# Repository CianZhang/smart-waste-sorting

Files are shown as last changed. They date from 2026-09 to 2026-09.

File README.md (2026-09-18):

# 智能垃圾分类——2025 年全国大学生工程实践与创新能力大赛全国一等奖作品

**[▶ 项目演示视频（哔哩哔哩）](https://www.bilibili.com/video/BV18GobY2Efq/)**

项目于我大三期间完成，制作时间为 **2025 年 12 月至 2026 年 3 月**。我负责机械结构设计、STM32 程序编写，以及 YOLOv8 模型的训练与部署；队友 **ccy** 负责树莓派端程序，并在 **zsq** 学长已有 Qt 界面代码的基础上完成界面适配。

这个项目中，我投入最多时间的是机械结构的设计、装配和反复调整。本文既介绍制作方法，也保留实际遇到的问题，希望能为后续复刻和改进提供参考。

基于 **树莓派 5、YOLOv8、STM32F103RCT6 与 CoreXY** 的智能垃圾分类装置。通过视觉识别、托盘倾倒和机械爪抓取完成四类垃圾分拣，并提供触摸界面、投料检测及满载提示。

**[完整制作教程](docs/build-guide.md)** · **[STM32 工程](firmware/stm32/README.md)** · **[树莓派程序](software/raspberry-pi/README.md)** · **[机械模型](hardware/README.md)**

## 项目组成

- 2020 铝型材框架、CoreXY 双步进平台、四舵机机械爪。
- 双舵机托盘、四面同步挡板、红外光幕和四路超声波。
- STM32 控制运动、串口及传感器；树莓派执行 YOLOv8 推理和 Qt/QML 界面。
- 完整教程包含 70 张图片、28 个功能 IO 的接线表、动作参数与省赛程序详解。

## 目录
```text
.
├── README.md
├── docs/                       # 完整制作教程、结构和版本说明
│   ├── build-guide.md
│   └── assets/
├── firmware/stm32/             # 已解压的省赛 Keil 工程
├── software/raspberry-pi/       # 已解压的省赛 Python / QML 应用
├── hardware/mechanical/        # SolidWorks 零件、装配与 STL
├── tools/
│   ├── vision/                 # 图像推理和训练入口
│   ├── calibration/            # 坐标标定程序及采样表
│   └── dataset/legacy/         # 历史采集及标签处理脚本
├── datasets/                   # 配置模板和历史类别顺序
├── models/                     # 部署权重的位置及校验说明
├── references/                 # 厂商资料与机械参考设计索引
├── scripts/                    # 仓库结构检查
├── .github/ISSUE_TEMPLATE/      # 问题反馈模板
└── .local-archive/              # 本地原始资料，Git 忽略
```

## 树莓派环境配置

[SSH、Python 与 YOLOv8 安装命令](docs/raspberry-pi-yolov8-setup.md) · [完整 TXT](docs/搭建yolov8环境.txt)

## 开始制作

1. 按 [制作教程](docs/build-guide.md) 制作框架与机构，完成单模块接线和标定。

2. 在 Keil 中打开 `firmware/stm32/Project.uvprojx`，核对开发板时钟与引脚；已知修正点见教程。

3. 按 [模型说明](models/README.md) 准备 `software/raspberry-pi/yolo/best.pt`，核对类别名称。

4. 在树莓派准备应用依赖，检查摄像头、串口和显示环境，然后从仓库根目录启动：

   ```sh
   sh software/raspberry-pi/run.sh
   ```

5. 通过界面进入识别页完成串口解锁，确认回零与上电等待结束，再进行空载及投料测试。

脚本会切换到正确的应用目录，不需要修改应用中的 QML、模型及图片相对路径。依赖清单尚不是经过实机验证的版本锁定文件。

## 参与与致谢

提交改动时说明使用的硬件、软件及模型版本，记录实际测试结果；参见 [贡献说明](CONTRIBUTING.md)。

作者负责机械结构、STM32 及模型训练部署，队友 ccy 负责树莓派程序，Qt 界面基于 zsq 学长的工作。

使用的第三方资料与贡献者见 [第三方资料与致谢](THIRD_PARTY_NOTICES.md)。

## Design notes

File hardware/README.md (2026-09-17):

# 机械模型

`mechanical/` 保存本项目的 SolidWorks 零件、装配和 STL，保留原文件名及 `XY平台/`、`垃圾桶/` 子目录，避免主动打乱零件关系。

先读 [制作教程](../docs/build-guide.md)，再按自己的实物尺寸打印。打开装配后仍需在 SolidWorks 检查引用、配合和干涉；本次未执行 CAD 软件验证，也未生成未经检查的打印导出件。

Woodcore 参考包保存在本地归档，不混入本项目制造零件。参考来源见 [第三方资料与致谢](../THIRD_PARTY_NOTICES.md)。

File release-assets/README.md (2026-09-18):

# 完整资源下载

[GitHub Release](https://github.com/CianZhang/smart-waste-sorting/releases/tag/resources-v1)

部署权重已随源码仓库提供。以下大型附件需要从 Release 单独下载，源码 ZIP 不包含这些附件。

| 附件 | 大小 |
| --- | ---: |
| [training-data-and-history.zip](https://github.com/CianZhang/smart-waste-sorting/releases/download/resources-v1/training-data-and-history.zip) | 1483.67 MB |
| [stepper-motor-vendor-resources.zip](https://github.com/CianZhang/smart-waste-sorting/releases/download/resources-v1/stepper-motor-vendor-resources.zip) | 458.77 MB |
| [legacy-projects-and-provincial-originals.zip](https://github.com/CianZhang/smart-waste-sorting/releases/download/resources-v1/legacy-projects-and-provincial-originals.zip) | 202.93 MB |
| [1.mp4](https://github.com/CianZhang/smart-waste-sorting/releases/download/resources-v1/1.mp4) | 158.4 MB |
| [yolov8.zip.part001](https://github.com/CianZhang/smart-waste-sorting/releases/download/resources-v1/yolov8.zip.part001) | 1500.0 MB |
| [yolov8.zip.part002](https://github.com/CianZhang/smart-waste-sorting/releases/download/resources-v1/yolov8.zip.part002) | 1500.0 MB |
| [yolov8.zip.part003](https://github.com/CianZhang/smart-waste-sorting/releases/download/resources-v1/yolov8.zip.part003) | 978.8 MB |

## 附件用途

- `1.mp4`: 下载后放入 `software/raspberry-pi/qml/1.mp4`.
- `training-data-and-history.zip`: 训练图片、标签、历史权重、训练结果与训练工程，保留原始目录结构。不同轮次的类别顺序不可直接混用。
- `stepper-motor-vendor-resources.zip`: 张大头步进电机完整说明书、工具、例程和演示视频。
- `legacy-projects-and-provincial-originals.zip`: 旧版 STM32 工程（含编译产物）及省赛原始压缩包。
- `yolov8.zip.part001` 至 `part003`：原始 yolov8.zip 的字节分卷，必须全部下载后合并，不能单独解压。

## 合并 yolov8.zip

macOS / Linux:

```sh
cat yolov8.zip.part001 yolov8.zip.part002 yolov8.zip.part003 > yolov8.zip
```

Windows CMD:

```bat
copy /b yolov8.zip.part001+yolov8.zip.part002+yolov8.zip.part003 yolov8.zip
```

合并完成后可解压。完整文件的 SHA-256：

```text
67cd5b0eae3dfe495bd9983304eb3f1da0dc6049562c12e1c48cc26f418390c0  yolov8.zip
```

附件校验值见 [SHA256SUMS.txt](SHA256SUMS.txt)，来源、文件数量与大小见 [manifest.json](manifest.json)。macOS 使用 `shasum -a 256 -c SHA256SUMS.txt`，Linux 使用 `sha256sum -c SHA256SUMS.txt`。

本地附件实体保存在可见的 `release-assets/` 文件夹，Git 只记录说明与校验清单。原始资料保留在 `.local-archive/original/`。系统镜像与个人初始化资料不在本次发布范围内。历史代码和模型按原样提供，未执行程序或加载模型。

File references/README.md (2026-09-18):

# 参考资料索引

完整厂商资料保留在本地 `.local-archive/original/张大头步进电机资料/`，包含 ZDT_X42_V2、Emm_V5.0 及刷入教程。它们不随本仓库默认提交；接线前应根据实际使用的驱动器版本确认文档。

Woodcore 参考包位于本地 `.local-archive/original/建模/Woodcore XY-CORE by Rics_3D - 2555558/`。原始来源是 [Thingiverse 上的 Woodcore XY-CORE](https://www.thingiverse.com/thing:2555558)，相关来源见 [第三方资料与致谢](../THIRD_PARTY_NOTICES.md)。

STM32 参数参考 [ST 官方数据手册](https://www.st.com/resource/en/datasheet/stm32f103rc.pdf)。

厂商安装包、固件工具和完整镜像保留在本地归档。

## 补充资源下载

训练图片、标签、历史权重与结果、电机厂商完整资料、旧版工程及编译产物、省赛原始压缩包、展示视频和 `yolov8.zip` 已整理为 [GitHub Release 附件](https://github.com/CianZhang/smart-waste-sorting/releases/tag/resources-v1)。分类、还原方式与校验值见 [资源下载说明](../release-assets/README.md)。本地附件位于根目录可见的 `release-assets/` 文件夹，原始归档继续保留。部署权重 `software/raspberry-pi/yolo/best.pt` 已直接纳入源码仓库。

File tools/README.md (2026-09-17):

# 辅助工具

## 图像测试

从仓库根目录执行，输入图片不会连接相机或 STM32：

```sh
python3 tools/vision/test.py --source datasets/local/test_images
```

需要提前准备图片和 [部署模型](../models/README.md)。也可通过 `--weights` 指定其他本地权重，默认输出为 `outputs/test_result/result_0.jpg` 等。

## 训练

```sh
python3 tools/vision/train.py --weights models/local/initial.pt --data datasets/local/data.yaml --epochs 500
```

示例中的文件需要自行准备。训练和图像测试入口已改为显式传参，不再依赖原电脑的绝对目录。默认输出位于根目录 `outputs/`，由 Git 忽略。`--help` 不加载模型或第三方依赖。

## 坐标标定

`calibration/main.py` 用最小二乘拟合二维映射；`main.c` 与 Excel 表为对应资料。程序中的标定点来自既有机构，必须在新机构上重新采集，见制作教程。

## 历史采集与标签工具

`dataset/legacy/` 中保存采集、改名、标签映射和数据拆分脚本，以及 `classes.txt`。这些脚本保留历史路径和修改行为，用于查看制作过程；不要直接批量运行，其中部分会原地改写标签或重命名图片。

历史类别合并有不同版本，必须与权重类别定义核对；完整数据仍在本地归档。本次没有对数据集重新划分或改写标签。

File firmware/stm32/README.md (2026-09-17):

# STM32 省赛工程

使用 `Project.uvprojx`，目标器件为 STM32F103RC，控制板按 STM32F103RCT6 接线。工程记录的编译器为 ARMCC V5.06 update 5（build 528）。

- `User/main.c`：完整分拣入口。
- `Hardware/`：舵机、CoreXY、传感器、串口及动作组合。
- `System/`：延时与 TIM7 配置。
- `Start/`：启动文件及系统时钟。
- `Library/`：随工程保留的 STM32 标准外设库，版权头保留。

完整 IO 表、回零时序、角度、坐标及已知问题见 [制作教程](../../docs/build-guide.md)。目录中的文件不一定都参与编译，以工程文件列表为准；不要把同名 PWM 实现重复加入工程。

本目录按省赛源码保存，未自动应用教程里的控制逻辑修正。特别是第四路 Echo PB15 的初始化需要按教程处理。编译缓存和个人 Keil 窗口状态不纳入 Git。

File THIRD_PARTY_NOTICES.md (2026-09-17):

# 第三方资料与致谢

| 内容 | 来源或作者 | 说明 |
| --- | --- | --- |
| 树莓派端程序 | ccy | 省赛应用实现 |
| Qt 界面基础 | zsq | 界面基础与适配参考 |
| Ultralytics YOLO | 项目已有框架副本，版本字符串 8.2.10 | 完整框架留在本地归档，应用通过依赖安装 |
| STM32 标准外设库与启动支持 | 随省赛工程保留的 ST / Arm 相关文件 | 支持控制器初始化与外设驱动 |
| Woodcore XY-CORE | Rics_3D，Thingiverse 2555558 | CoreXY 结构参考，完整参考包留在本地归档 |
| 驱动器手册及工具 | 张大头/Emm 相关资料包 | 本地归档提供硬件参考 |
| OpenCV、pyserial、PySide6 | Python 应用依赖 | 图像处理、串口通信和 Qt 界面 |

感谢以上贡献者及项目提供的代码、设计与资料。

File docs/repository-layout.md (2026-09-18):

# 目录迁移说明

项目根目录仍为原来的“工训赛”文件夹。制作资料组织为公开项目内容和本地原始归档两部分。

## 主要入口

| 内容 | 新位置 |
| --- | --- |
| 项目首页 | [README](../README.md) |
| 详细制作教程 | [build-guide.md](build-guide.md) |
| 教程图片 | `docs/assets/` |
| STM32 工程 | [固件说明](../firmware/stm32/README.md) |
| 树莓派应用 | [应用说明](../software/raspberry-pi/README.md) |
| 机械模型 | [模型目录说明](../hardware/README.md) |
| 训练、测试与标定 | [工具说明](../tools/README.md) |

## 环境配置资料

树莓派 YOLOv8 安装记录已纳入公开目录：[环境配置文档](raspberry-pi-yolov8-setup.md) 与 [完整 TXT](搭建yolov8环境.txt)。TXT 与本地归档文件内容一致。

## 原资料保留位置

所有整理前的根目录项目整体移入 `.local-archive/original/`，保持其原有子目录关系。没有删除原文件，系统镜像和数据也没有重复复制到公开项目。

| 整理前位置 | 原始副本位置 | 提供的公开入口 |
| --- | --- | --- |
| `工训赛-智能垃圾分类.md` | `.local-archive/original/工训赛-智能垃圾分类.md` | `docs/build-guide.md` |
| `工训赛-智能垃圾分类.assets/` | `.local-archive/original/工训赛-智能垃圾分类.assets/` | `docs/assets/` |
| `建模/` | `.local-archive/original/建模/` | `hardware/mechanical/`，独立参考包除外 |
| `代码/省赛代码/` | `.local-archive/original/代码/省赛代码/` | 已解压到固件和应用目录 |
| `代码/坐标映射/` | `.local-archive/original/代码/坐标映射/` | `tools/calibration/` |
| `代码/get_photo/` | `.local-archive/original/代码/get_photo/` | `tools/dataset/legacy/` |
| `代码/树莓派/` | `.local-archive/original/代码/树莓派/` | 可移植入口位于 `tools/vision/` |
| 旧工程、训练数据、镜像、安装包 | `.local-archive/original/代码/` | 本地归档，Git 忽略 |
| `张大头步进电机资料/` | `.local-archive/original/张大头步进电机资料/` | `references/README.md` 提供索引 |

`.local-archive/inventory-before.json` 记录迁移前的相对路径、大小和修改时间；`migration-report.json` 记录整理时的验证结果。两者只保存在本地归档。

## 提交范围

`.gitignore` 排除本地归档、模型、展示视频、推理图片、构建缓存和个人环境文件。部署权重纳入源码仓库，展示视频通过 Release 下载。

公开仓库只包含上述整理后的项目内容；本地原始归档不随 Git 提交上传。

## 补充资源下载

训练图片、标签、历史权重与结果、电机厂商完整资料、旧版工程及编译产物、省赛原始压缩包、展示视频和 `yolov8.zip` 已整理为 [GitHub Release 附件](https://github.com/CianZhang/smart-waste-sorting/releases/tag/resources-v1)。分类、还原方式与校验值见 [资源下载说明](../release-assets/README.md)。本地附件位于根目录可见的 `release-assets/` 文件夹，原始归档继续保留。部署权重 `software/raspberry-pi/yolo/best.pt` 已直接纳入源码仓库。

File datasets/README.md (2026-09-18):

# 数据集与类别配置

完整训练数据留在本地 `.local-archive/original/代码/` 中。新增数据放在 `datasets/local/`，Git 默认忽略该目录。

- `data.example.yaml`：按历史 `classes.txt` 整理的十类模板，必须改路径并核对标签后使用。
- `config-history/`：三轮训练的四类名称和顺序快照；路径使用 `<DATASET_ROOT>` 占位，不能直接拿来训练。

不同轮次的类别编号顺序存在差异，不能仅因为都是四类就互换 YAML、标签和权重。省赛应用按具体物体名称映射到四大类，详见制作教程。

发布数据时应补充来源、类别定义及使用范围。各轮训练质量以实际测试结果为准。

## 补充资源下载

训练图片、标签、历史权重与结果、电机厂商完整资料、旧版工程及编译产物、省赛原始压缩包、展示视频和 `yolov8.zip` 已整理为 [GitHub Release 附件](https://github.com/CianZhang/smart-waste-sorting/releases/tag/resources-v1)。分类、还原方式与校验值见 [资源下载说明](../release-assets/README.md)。本地附件位于根目录可见的 `release-assets/` 文件夹，原始归档继续保留。部署权重 `software/raspberry-pi/yolo/best.pt` 已直接纳入源码仓库。

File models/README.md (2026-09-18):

# 模型权重

部署模型位于 `software/raspberry-pi/yolo/best.pt`，已纳入 Git 仓库，克隆项目即可获得该部署权重。

| 项目 | 内容 |
| --- | --- |
| 来源 | 省赛 Python 3.19 压缩包中的 `yolo/best.pt` |
| 文件大小 | 22536814 字节 |
| SHA-256 | `0e9ade16c99730c9233939a2b89183e47f08c946b4a3c8519184833ff6c6b524` |

原压缩包留在本地 `.local-archive/original/代码/省赛代码/`。原始压缩包与历史训练资料同时提供于 [GitHub Release](https://github.com/CianZhang/smart-waste-sorting/releases/tag/resources-v1)，文件说明见 [资源下载说明](../release-assets/README.md)。

程序使用模型中的物体名称映射到四类垃圾，部署前核对 `model.names`。历史数据含不同类别体系，不能仅按文件名 `best.pt` 判断是否匹配。

自行训练的权重可以暂存于 `models/local/`，该目录由 Git 忽略。没有执行加载或推理验证，也没有从不可信的模型文件反序列化内容。

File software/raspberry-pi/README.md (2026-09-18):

# 树莓派省赛应用

应用入口为本目录的 `main.py`。`qml/main.py` 是另一个界面入口，不作为完整系统启动入口。

## 环境配置命令

项目保存的 Ubuntu 24.04.1 LTS、Python 3.10.16 和 YOLOv8 配置命令已整理为 [环境配置文档](../../docs/raspberry-pi-yolov8-setup.md)，也可查看 [完整 TXT](../../docs/搭建yolov8环境.txt)。这份记录覆盖 YOLOv8 安装；Qt 应用依赖仍需按下文准备。

## 运行准备

需要 ultralytics、OpenCV、pyserial 和 PySide6，依赖名称列在 `requirements.txt`。操作系统、Python、PyTorch 和 Qt 的具体组合仍需在目标树莓派验证，没有把未核实的版本标为可复现环境。

确认以下条件后，从仓库根目录运行：

```sh
sh software/raspberry-pi/run.sh
```

可以通过 `PYTHON` 指定已经配置好的解释器。启动器只切换工作目录并准备结果图片目录，不自动安装软件、不自动修改硬件设置。

| 资源/配置 | 当前使用位置 |
| --- | --- |
| 模型 | `yolo/best.pt` |
| 摄像头 | `main.py` 中 `cv.VideoCapture(0)` |
| 串口 | `main.py` 中 `/dev/ttyAMA0`、115200 |
| 界面 | `qml/main.qml`，布局为 1280 × 800 |
| 推理图片 | `yolo/pics/`，Git 忽略 |
| 展示视频 | `qml/1.mp4`，Git 忽略 |

## 模型和视频

部署模型 `yolo/best.pt` 已纳入 Git 仓库。展示视频请从 [GitHub Release](https://github.com/CianZhang/smart-waste-sorting/releases/tag/resources-v1) 下载 `1.mp4`，放到本目录的 `qml/1.mp4`。

模型来源与校验值见 [模型说明](../../models/README.md)。展示页使用 `qml/1.mp4`，下载后保持文件名和位置一致；不使用展示页时可相应调整界面。没有视频不代表视觉识别代码或模型缺失。

省赛原始压缩包及历史结果图位于本地归档，具体位置见 [目录迁移说明](../../docs/repository-layout.md)。

## 已知行为

代码保留省赛识别和计数逻辑。首次未识别到目标时随机分类、识别前置计数、串口超时不足等问题已在 [完整教程](../../docs/build-guide.md) 中说明。运行前先做模块测试，不把桌面静态检查当作整机验证。

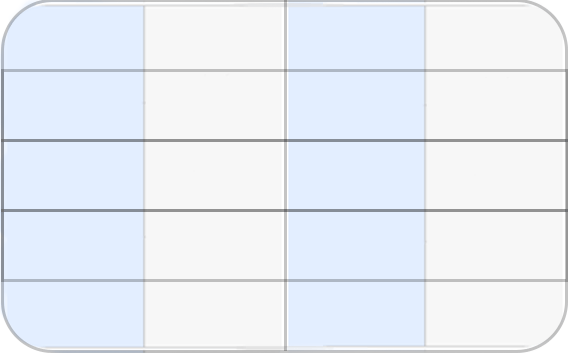
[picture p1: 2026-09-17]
software/raspberry-pi/qml/UI_2.1/p2/images/Page2_15.png

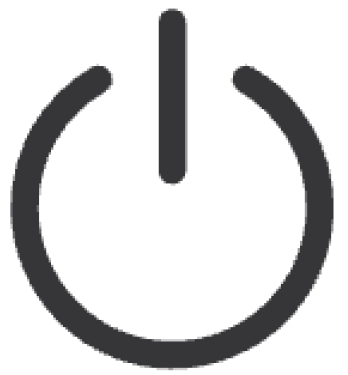
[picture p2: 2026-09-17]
software/raspberry-pi/qml/UI_2.1/p2/images/关机2.png

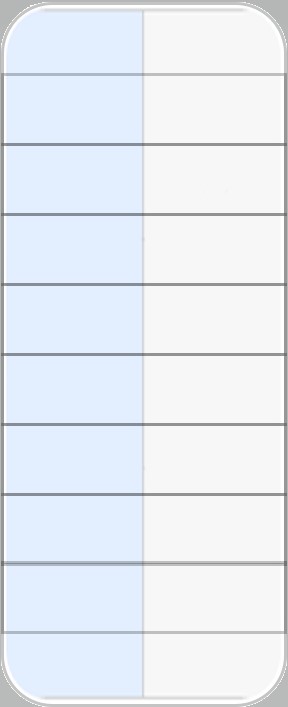
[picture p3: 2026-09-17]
software/raspberry-pi/qml/UI_2.1/p2/images/Page2_05.jpg

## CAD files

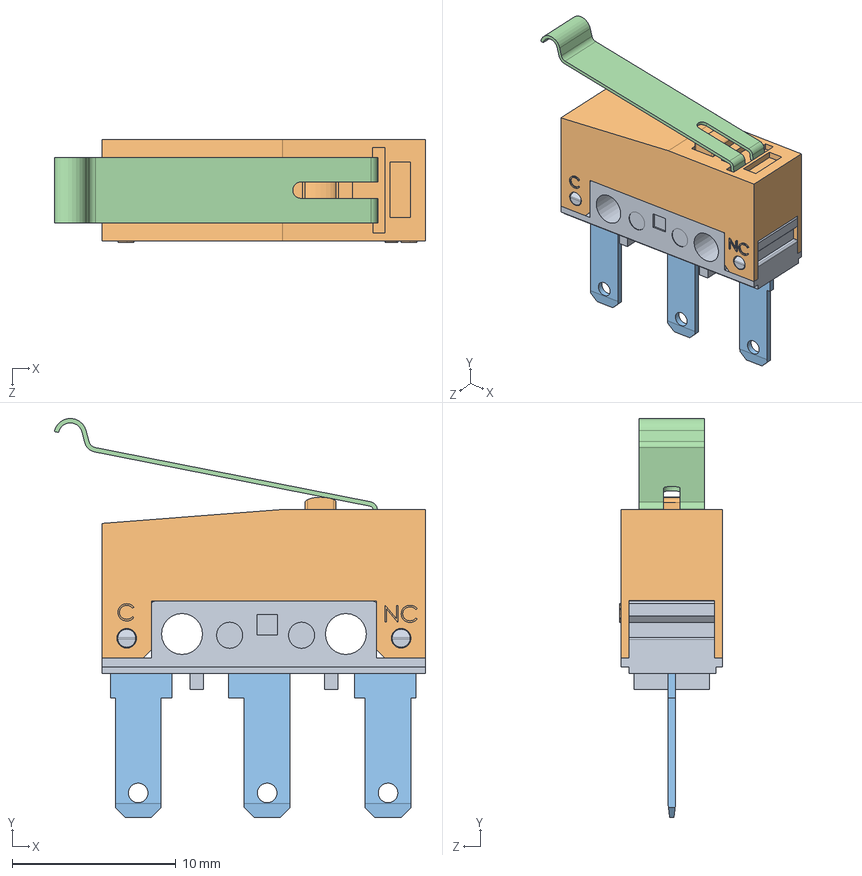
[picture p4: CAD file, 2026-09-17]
hardware/mechanical/垃圾桶/Microswitch-SS-3GL13SL.SLDASM
22.7 x 24.4 x 6.30 mm
limit-switch-bottomcase
limit-switch-top-case
pins
switch_lever

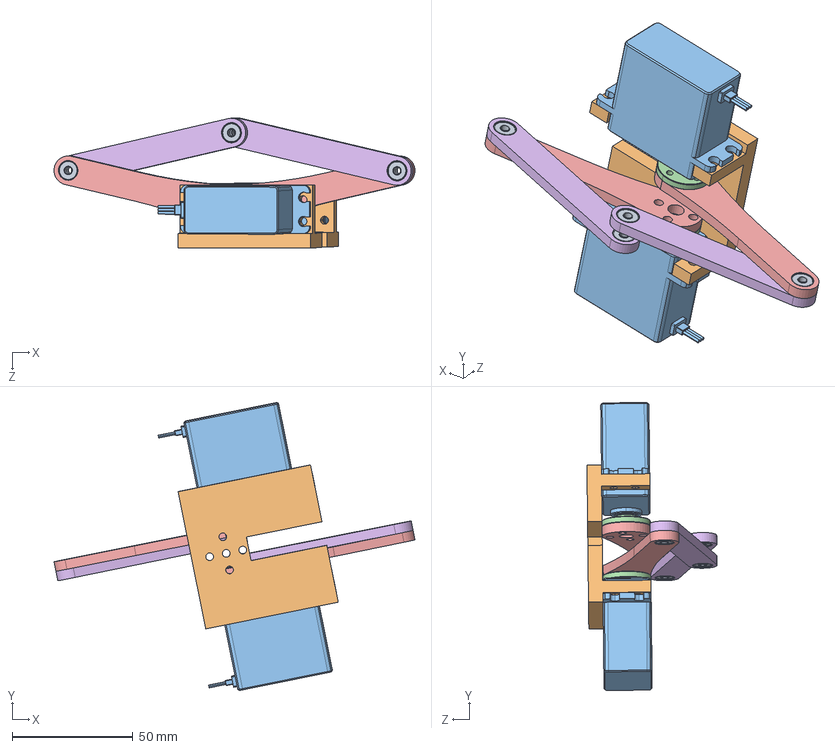
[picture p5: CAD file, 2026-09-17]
hardware/mechanical/垃圾桶/机械爪上.SLDASM
149.6 x 119.3 x 53.9 mm
M3ￖ᳐' x 6
ﾶ滺' x 2
¶æ_Ì x 2
连杆1 x 2
连杆2 x 2

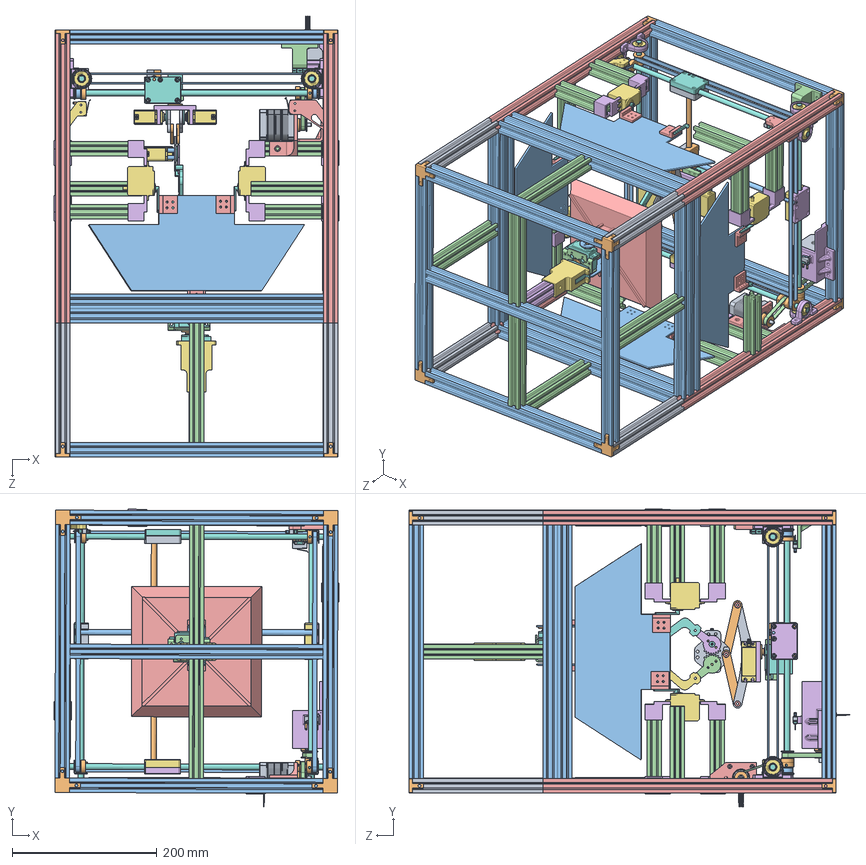
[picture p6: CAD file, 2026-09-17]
hardware/mechanical/垃圾桶/垃圾桶.SLDASM
393.4 x 410.9 x 609.0 mm
11NhomDinhHinh2020（180mm） x 4
欧标2020三维连接件 x 8
11NhomDinhHinh2020（350mm） x 17
11NhomDinhHinh2020（165mm） x 6
11NhomDinhHinh2020（400mm） x 4
11NhomDinhHinh2020（120mm）
11底部舵机固定
11servo x 3
11shaft x 3
Servo disc x 3
11Servo Bracket - long U v3
Servo Bracket - universal.step
托盘
11KP08 x 8
11608RS x 8
8mm光轴（长384mm） x 4
十字滑块1
十字滑块2
8mm光轴（长336mm）
11LM8LUU Long Type Linear Bearing（长24）
11LM8LUU Long Type Linear Bearing x 4
11滑块_右 x 2
11滑块_右盖 x 2
11滑块_左 x 2
11滑块_左盖 x 2
8mm光轴（长335.9mm）
12 8 20铜套
11机械臂单舵机固定
M3ￖ᳐' x 6
ﾶ滺' x 3
¶æ_Ì x 3
连杆1 x 2
连杆2 x 2
Ì×2 x 4
צϰ￫2'
Ì×
צϰ￫'
ￂצ'
抓手左
零件3
同步轮8mm x 10
挡板 x 4
11铝型材2020长100 x 12
11挡板固定 x 8
11舵机铝型材支架 x 8
11舵机1 x 4
11长款舵机固定 x 8
1142BYGH0425 x 2
步进电机同步轮 x 2
同步带示意 x 4
同步带示意上 x 2
步进电机固定架下
步进电机固定架上
碰撞开关固定1
limit-switch-bottomcase x 4
limit-switch-top-case x 4
pins x 4
switch_lever x 4
碰撞开关固定2
碰撞开关固定3

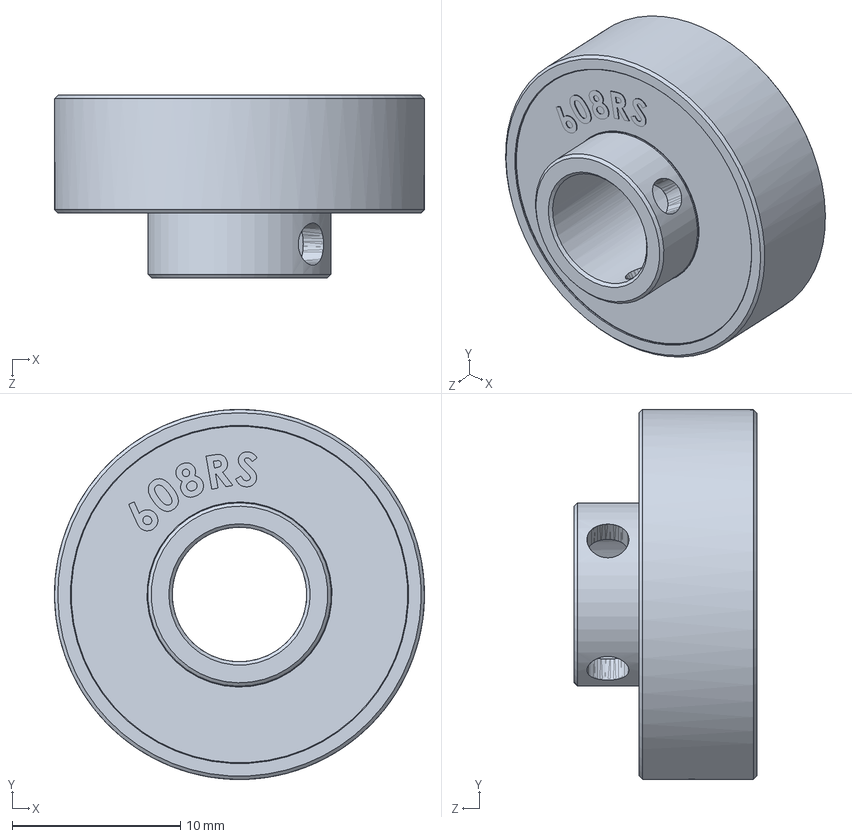
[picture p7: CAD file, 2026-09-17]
hardware/mechanical/垃圾桶/11KP08.SLDASM
22.0 x 22.0 x 10.9 mm

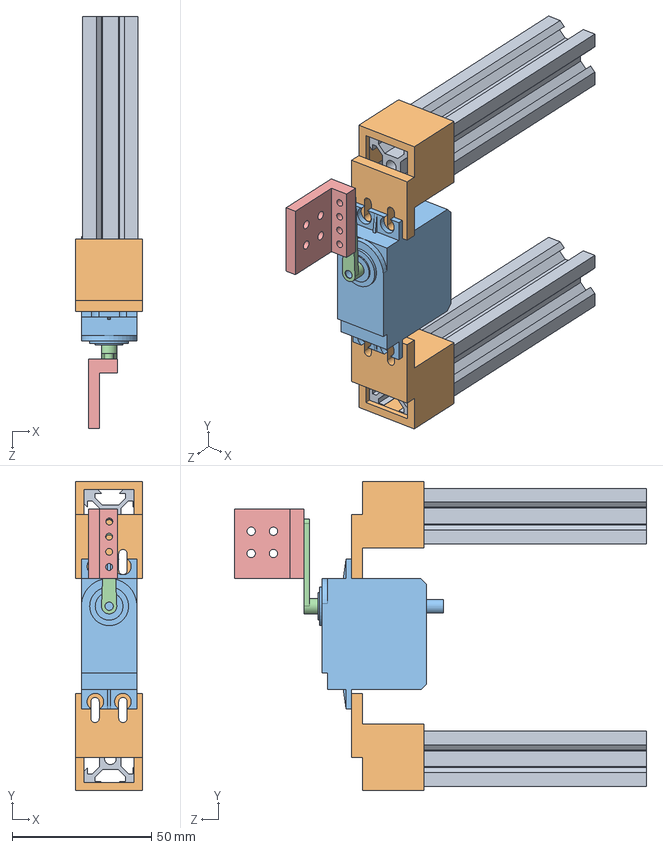
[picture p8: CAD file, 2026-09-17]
hardware/mechanical/垃圾桶/挡板固定舵机.SLDASM
24.0 x 111.2 x 148.1 mm
11铝型材2020长100 x 2
11舵机铝型材支架 x 2
11舵机1
11长款舵机固定
11挡板固定

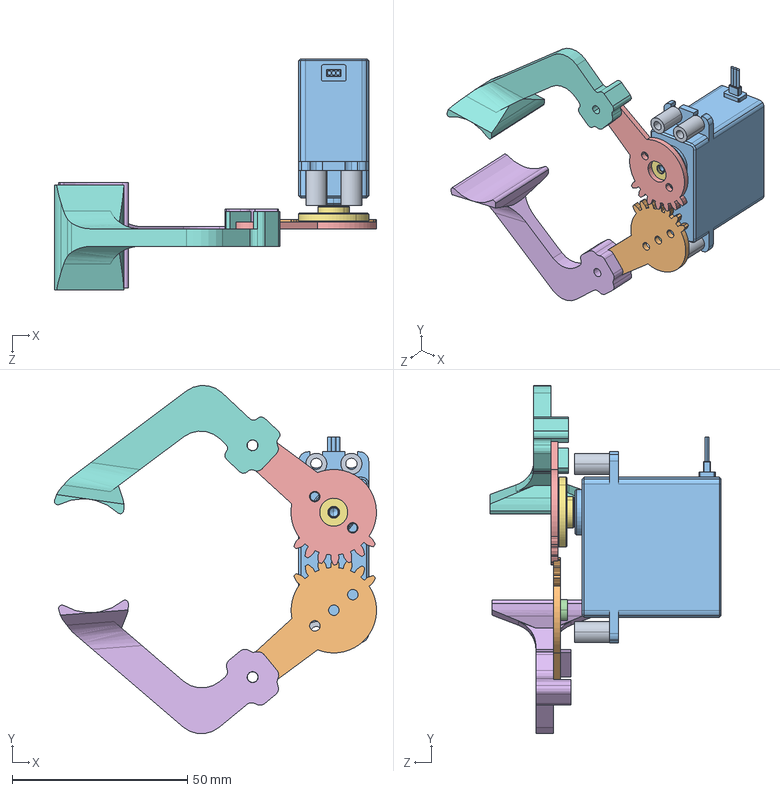
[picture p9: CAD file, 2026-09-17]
hardware/mechanical/垃圾桶/机械爪下.SLDASM
91.9 x 99.2 x 66.0 mm
Ì×2 x 4
צϰ￫2'
ﾶ滺'
Ì×
צϰ￫'
ￂצ'
¶æ_Ì
抓手左

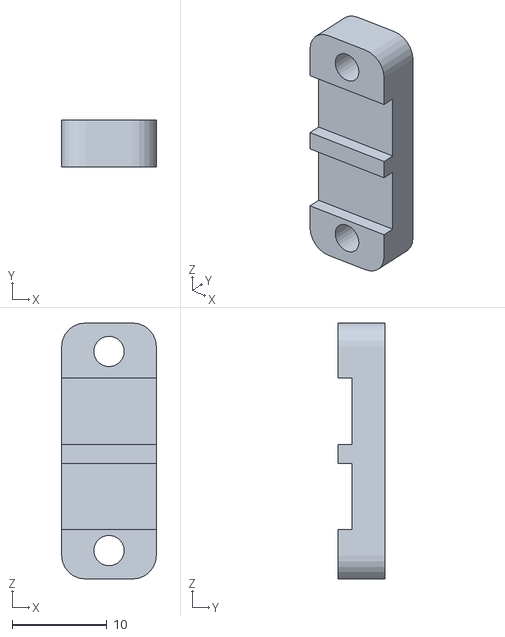
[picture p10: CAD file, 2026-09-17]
hardware/mechanical/XY平台/Riemenklammer.stl
10.0 x 5.00 x 27.0

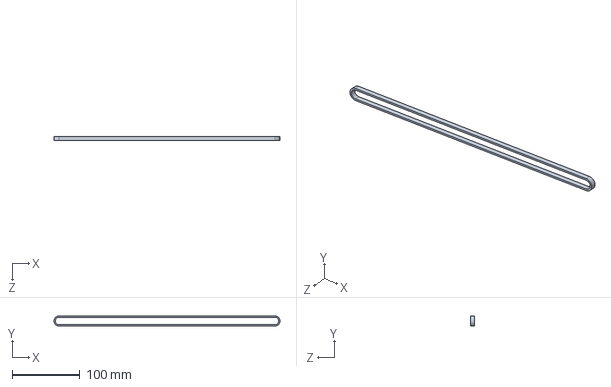
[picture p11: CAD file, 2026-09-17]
hardware/mechanical/垃圾桶/同步带示意.SLDPRT
332.9 x 15.0 x 6.00 mm

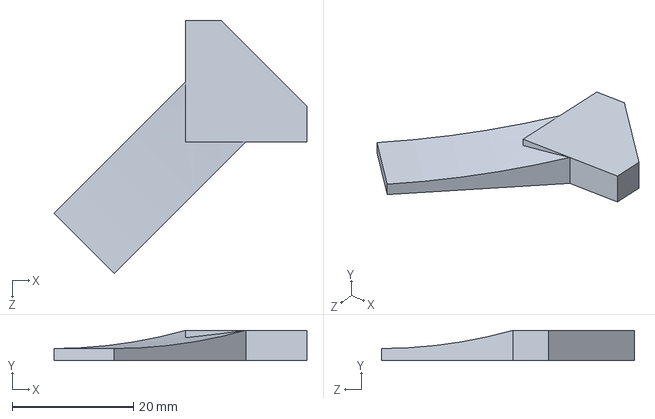
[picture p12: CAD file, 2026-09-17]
hardware/mechanical/超声波固定.SLDPRT
41.7 x 5.00 x 41.7 mm

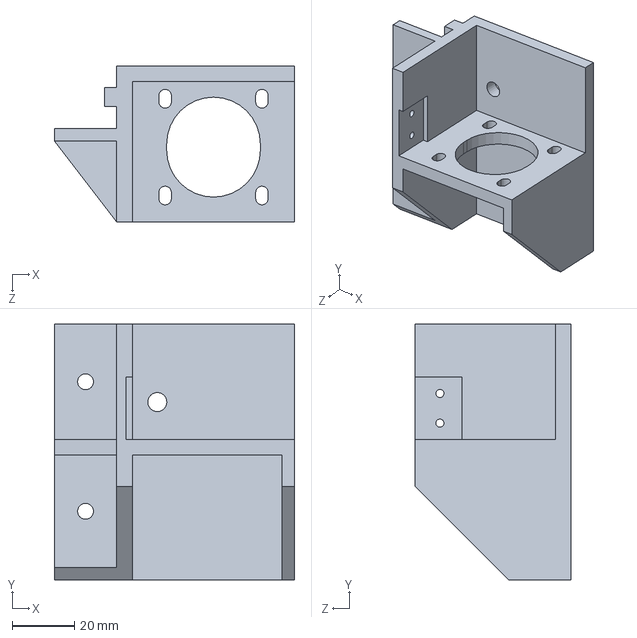
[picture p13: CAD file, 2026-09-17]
hardware/mechanical/XY平台/步进电机支架左.SLDPRT
77.0 x 82.0 x 50.0 mm

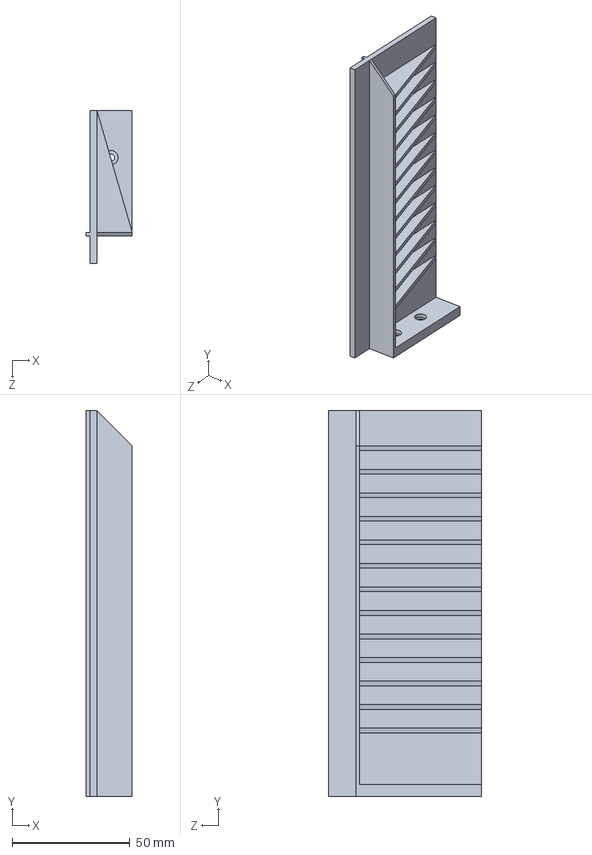
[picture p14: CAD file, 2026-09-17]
hardware/mechanical/压缩面挡板.SLDPRT
19.8 x 164.0 x 65.0 mm

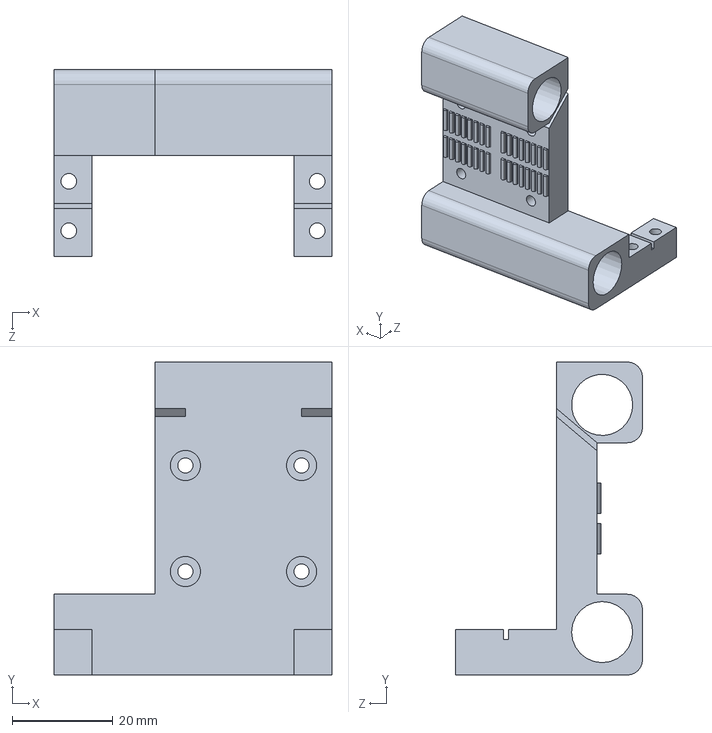
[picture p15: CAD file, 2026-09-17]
hardware/mechanical/XY平台/中心轴 - 副本.SLDPRT
55.0 x 62.0 x 37.0 mm

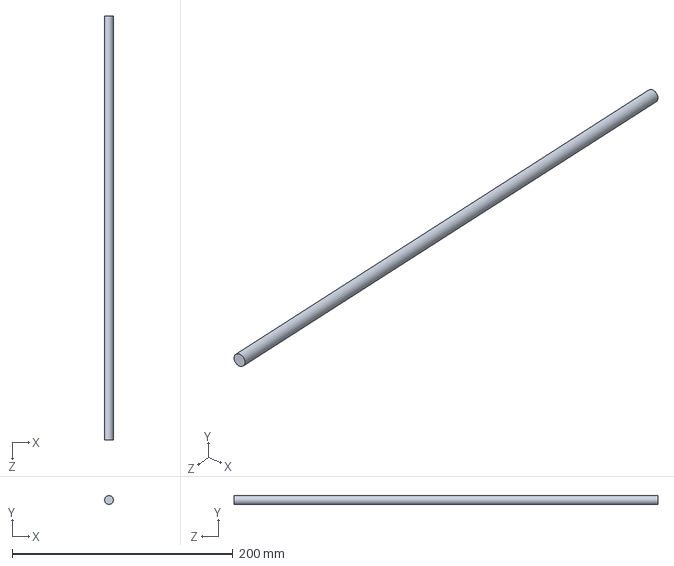
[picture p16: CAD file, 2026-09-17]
hardware/mechanical/垃圾桶/8mm光轴（长384mm）.SLDPRT
8.00 x 8.00 x 384.0 mm

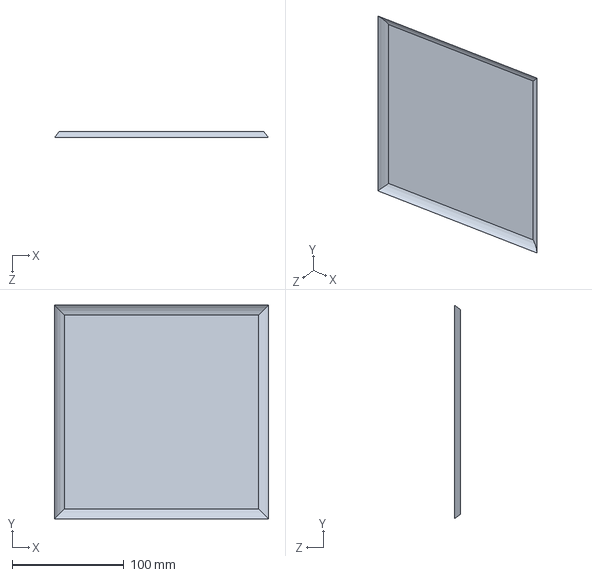
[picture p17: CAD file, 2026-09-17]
hardware/mechanical/托盘覆盖圆滑.SLDPRT
191.3 x 191.3 x 5.79 mm

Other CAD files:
hardware/mechanical/垃圾桶/11MG996R.SLDASM
hardware/mechanical/LED固定.SLDPRT
hardware/mechanical/XY平台/y轴右.SLDPRT
hardware/mechanical/垃圾桶/11机械臂单舵机固定.SLDPRT
hardware/mechanical/XY平台/y轴左.SLDPRT
hardware/mechanical/XY平台/惰轮替代.SLDPRT
hardware/mechanical/XY平台/步进电机支架右.SLDPRT
hardware/mechanical/XY平台/滑轨支架右.SLDPRT
hardware/mechanical/XY平台/滑轨支架左.SLDPRT
hardware/mechanical/侧面柱子固定.SLDPRT
hardware/mechanical/侧面舵机固定.SLDPRT
hardware/mechanical/压缩杆固定.SLDPRT
hardware/mechanical/压缩面.SLDPRT
hardware/mechanical/垃圾桶/1.sldprt
hardware/mechanical/垃圾桶/1142BYGH0425.SLDPRT
hardware/mechanical/垃圾桶/11608RS.SLDPRT
hardware/mechanical/垃圾桶/11KP08.SLDPRT
hardware/mechanical/垃圾桶/11LM8LUU Long Type Linear Bearing.SLDPRT
hardware/mechanical/垃圾桶/11LM8LUU Long Type Linear Bearing（长24）.SLDPRT
hardware/mechanical/垃圾桶/11NhomDinhHinh2020（120mm）.SLDPRT
hardware/mechanical/垃圾桶/11NhomDinhHinh2020（165mm）.SLDPRT
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

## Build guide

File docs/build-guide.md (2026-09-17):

# 工训赛智能垃圾分类装置：从结构制作到省赛程序部署

本项目使用 **树莓派 5 + YOLOv8** 识别垃圾，通过 **STM32F103RCT6、CoreXY 平台、四舵机机械爪和二维云台** 完成分拣，并使用红外光幕、超声波传感器和 Qt 界面实现投料检测、满载提示及操作交互。

项目在我大三期间完成，制作时间为 **2025 年 12 月至 2026 年 3 月**。我负责机械结构设计、STM32 程序以及 YOLOv8 模型训练与部署；队友 **ccy** 负责树莓派端代码，并基于 **zsq** 学长的 Qt 界面完成适配。

本文按实际制作顺序介绍零件、装配、接线、标定和软件流程。软件说明以 `firmware/stm32/` 与 `software/raspberry-pi/` 中展开的 **省赛 3.19 版本**为依据。部分照片属于制作过程中的不同阶段，安装前应核对模型孔位、尺寸和自己的实物。尚未确认的采购规格不作为固定型号推荐。

## 目录

- [系统如何完成一次分拣](#系统如何完成一次分拣)
- [项目文件与制作准备](#项目文件与制作准备)
- [物料清单](#物料清单)
- [机械装配过程](#机械装配过程)
- [STM32F103RCT6 接线与供电](#stm32f103rct6-接线与供电)
- [省赛 STM32 程序详解](#省赛-stm32-程序详解)
- [树莓派视觉、Qt 界面与模型训练](#树莓派视觉qt-界面与模型训练)
- [分阶段调试与整机制作验收](#分阶段调试与整机制作验收)
- [常见问题与待完善项](#常见问题与待完善项)
- [仓库整理与资料发布](#仓库整理与资料发布)
- [致谢与第三方资料](#致谢与第三方资料)

## 系统如何完成一次分拣

投入口红外光幕检测到垃圾后，STM32 等待物体稳定，再请求树莓派拍照。树莓派识别物体类别和图像坐标：单个目标或全部同类时，控制托盘整体倾倒；存在不同类别时，先抓取一个目标，再重新识别剩余垃圾。倾倒后还会检查残留，最后进行满载检测并回到待机。

```mermaid
flowchart TD
    A[上电初始化与机械回零] --> B[串口解锁且等待约15秒]
    B --> C[等待红外投料触发]
    C --> D[等待2秒并发送 Start]
    D --> E[树莓派拍照识别]
    E -->|单个或全部同类| F[按类别倾倒]
    E -->|不同类别混合| G[按坐标抓取一个]
    G --> D2[再次发送 Start]
    D2 --> E
    F --> H[发送 Check 复检]
    H -->|还有目标| I[按坐标抓取残留]
    I --> H
    H -->|无目标返回9| J[满载检测与复位]
    J --> C
```

这张图描述正常识别路径。首次识别没有目标时的程序行为及其处理办法，见树莓派程序章节。

| 模块 | 制作内容 |
| --- | --- |
| 框架 | 2020 欧标铝型材、打印连接件和外壳 |
| 视觉 | 摄像头、树莓派 5、YOLOv8 模型、固定补光 |
| 水平移动 | CoreXY、两套步进电机及驱动器、回零限位 |
| 机械爪 | 旋转、双舵机伸缩、夹爪开合，共 4 个舵机 |
| 托盘 | 水平旋转与俯仰，共 2 个舵机 |
| 挡板 | 4 个舵机同步开合 |
| 检测 | 红外光幕、4 路独立触发超声波 |
| 交互 | 触摸屏、Qt/QML、工作灯及调试 OLED |
| 供电 | 锂电池、电源转换与上下部分配电 |

## 项目文件与制作准备

```text
工训赛/
├── README.md
├── docs/build-guide.md       # 本文
├── docs/assets/              # 制作图片
├── firmware/stm32/           # 省赛 Keil 工程
├── software/raspberry-pi/     # 省赛 Python 与 QML
├── hardware/mechanical/      # SolidWorks、STL 等
│   ├── XY平台/
│   └── 垃圾桶/
├── tools/vision/             # 图像测试、训练
├── tools/calibration/        # 坐标映射和采样表
├── tools/dataset/legacy/     # 历史采集和标签处理
├── datasets/                 # 配置模板与类别历史
├── models/                   # 权重说明
├── references/               # 参考资料索引
└── .local-archive/original/   # 完整原始资料，仅本地保留
```

开始制作前，先准备可以查看和编辑 SolidWorks 模型的环境，确认自己要打印的零件版本，再制作型材和物料清单。工具包括装配螺丝工具、测量工具、焊接工具、万用表、3D 打印设备或打印服务，以及用于下载固件的调试器。需要切割光杆时，还要准备对应的切割与去毛刺工具。

制作时遵循模块逐个完成的顺序：先机械试装，再电气单独测试，最后进行整机联调。相机坐标标定安排在摄像头、托盘和机械回零位置都稳定之后。

## 物料清单

以下为单台装置的主要物料。采购截图用于对照历史方案，截图中的下单数量不一定等于单台设备用量。型号不明确的零件，应先检查装配模型和实物接口，再确定采购规格。

| 物料 | 数量或要求 | 用途与备注 |
| --- | --- | --- |
| 树莓派 5 | 1 块 | 视觉识别与界面 |
| STM32F103RCT6 控制板 | 1 块 | 按本文 IO 表接线，板上电源接口以实物标识为准 |
| 树莓派供电模块 | 1 块 | 本机方案由 12 V 电池输入；输出规格及兼容性按实际模块确认 |
| DC 电源模块 | 2 块 | 上、下部机构分组供电；输出电压与额定电流待确认 |
| 12 V 锂电池 | 1 组 | 比赛时另备两组用于比赛轮换 |
| 2020 欧标铝型材 | 按框架图裁切 | 配套角码、槽用螺母和螺栓 |
| 舵机 | 10 个 | 机械爪 4 个、挡板 4 个、二维云台 2 个 |
| 步进电机及驱动器 | 2 套 | 本机方案使用张大头驱动方案，具体版本待确认 |
| 延时上电继电器 | 1 路 | 控制其中一台步进电机的上电时序 |
| 限位开关 | 2 个 | 平台回零 |
| 6 mm 光杆 | 按模型裁切 | CoreXY 导向；切割长度待确认 |
| 直线轴承 | 约 4 个，需核对模型 | 型号需按轴径、外径、长度共同核对 |
| 同步带 | 2 条 | 长度、带宽、齿距按模型核对 |
| 第一类带齿轮 | 6 个，可准备 8 个 | 型号见采购图，须核对孔径与齿形 |
| 第二类带齿轮 | 2 个，可准备 4 个 | 型号见采购图 |
| 无齿惰轮 | 4 个 | 原采购图未完整展示 |
| 摄像头 | 1 个 | 最终镜头视场角待确认 |
| 红外光幕 | 1 套 | 投入口检测 |
| HC-SR04 | 4 个 | 四个收集桶满载检测 |
| 6810ZZ 轴承 | 1 个 | 托盘旋转机构，按模型复核配合尺寸 |
| 夹爪、舵盘、云台铝合金件 | 按装配需求 | 不额外增加上述舵机总数 |
| 调试 OLED | 1 块，可按需要保留 | 接 PB8/PB9，显示超声波距离 |
| 触摸显示器 | 1 块 | 原设备采用 HDMI、USB 触控和 12 V 供电，型号不详 |
| 显示连接线 | 按接口配置 | 连接树莓派与显示器 |
| WS2812 灯板 | 3 块 | 内部补光 |
| Arduino 控制板 | 1 块 | 本机方案的补光控制器 |
| 线材、可插拔接头、线束固定件、方管 | 按走线需求 | 按线束实际长度及电流选择线径 |
| 3D 打印耗材 | 按模型需求 | 托盘覆盖件使用黑色材料 |
| 亚克力板、装饰板和压条 | 按外壳需求 | 外观与遮光；不影响功能的装饰可省略 |
| 12 V 电动推杆 | 可省略 | 原压缩方案供电不稳定，比赛未使用 |

### 原始采购截图

#### 1. 树莓派供电模块

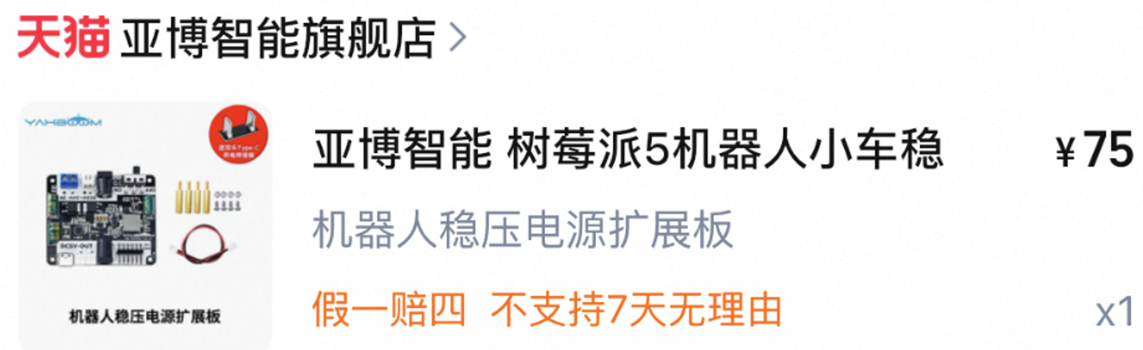
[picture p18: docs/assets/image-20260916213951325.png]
树莓派供电模块（图1）


#### 2. 树莓派 5

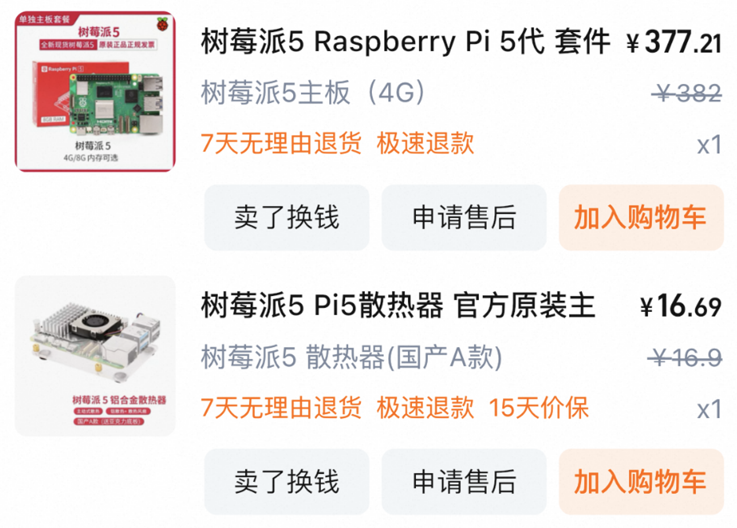
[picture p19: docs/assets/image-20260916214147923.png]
树莓派 5（图1）


#### 3. 2020 铝型材与角码

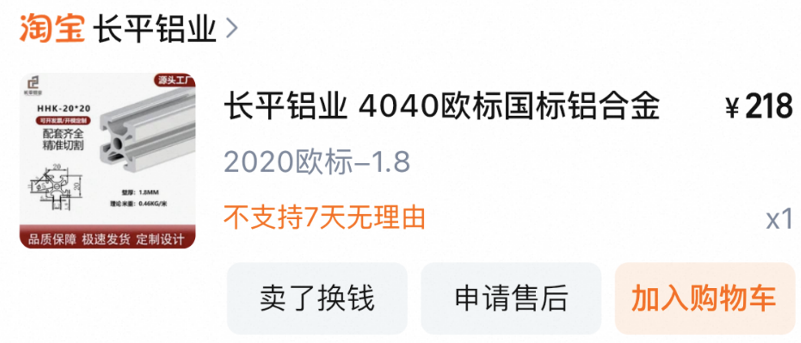
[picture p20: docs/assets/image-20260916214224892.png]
2020 铝型材与角码（图1）


#### 4. 舵机，共 10 个

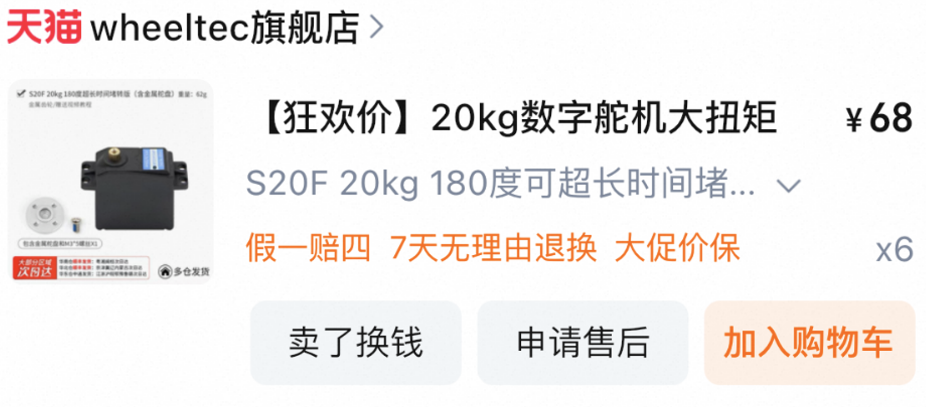
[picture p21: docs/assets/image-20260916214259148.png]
舵机，共 10 个（图1）


#### 5. 投入口红外光幕

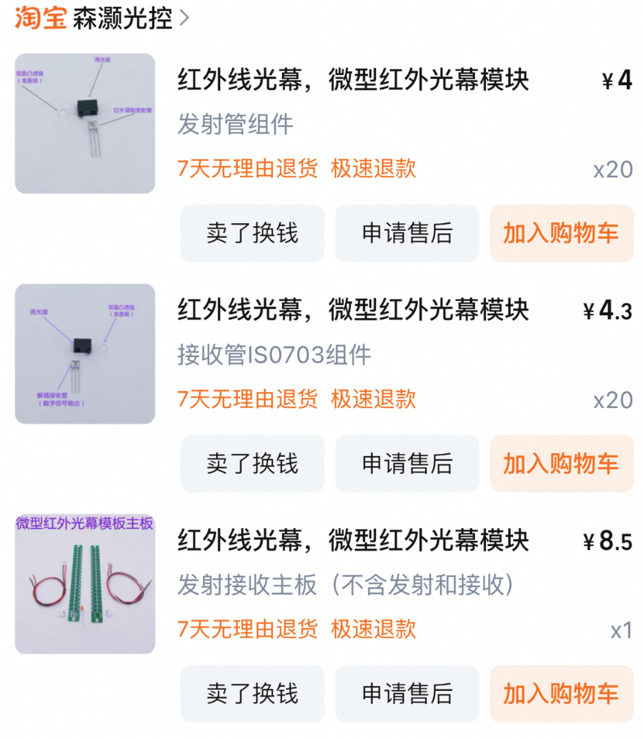
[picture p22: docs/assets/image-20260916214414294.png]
投入口红外光幕（图1）


#### 6. CoreXY 光杆

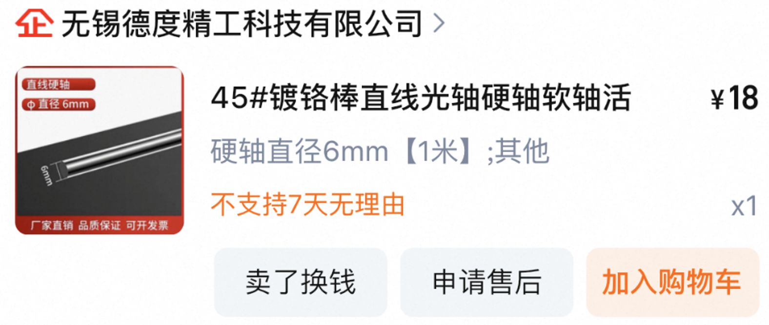
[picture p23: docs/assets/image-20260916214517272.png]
CoreXY 光杆（图1）


#### 7. 步进电机

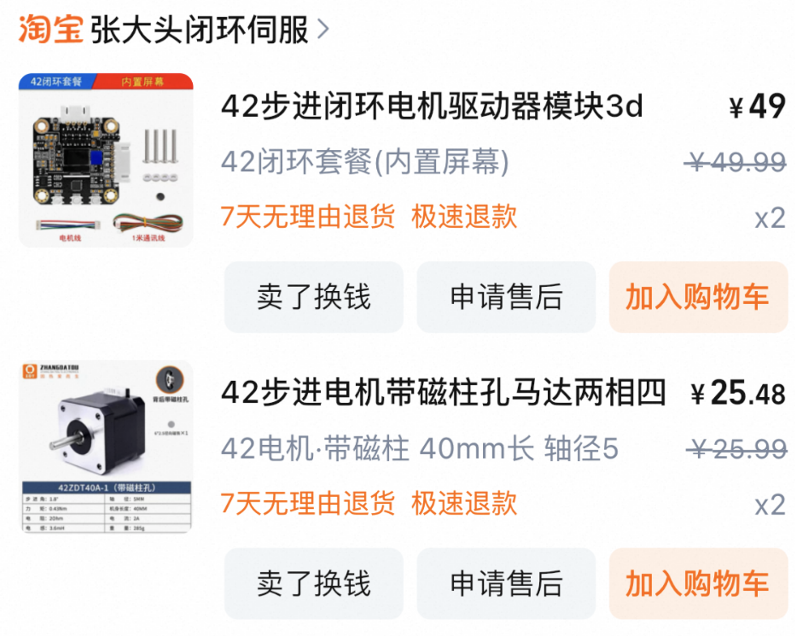
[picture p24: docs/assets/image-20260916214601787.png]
步进电机（图1）


#### 8. 线材与同步带

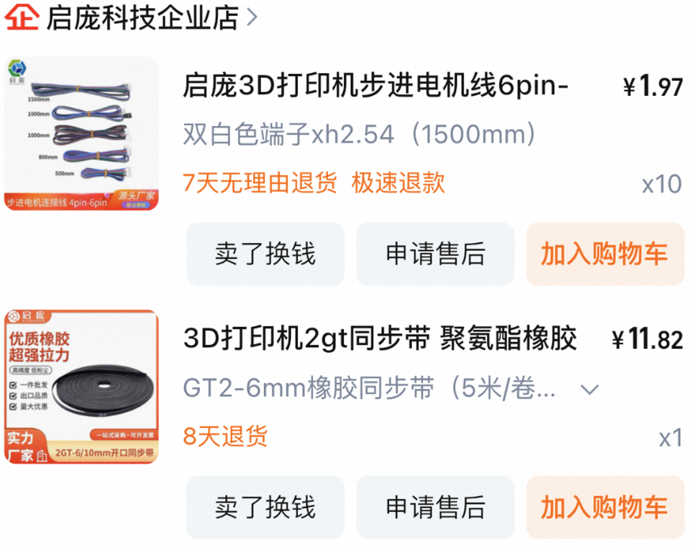
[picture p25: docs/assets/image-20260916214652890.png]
线材与同步带（图1）


#### 9. 12 V 锂电池

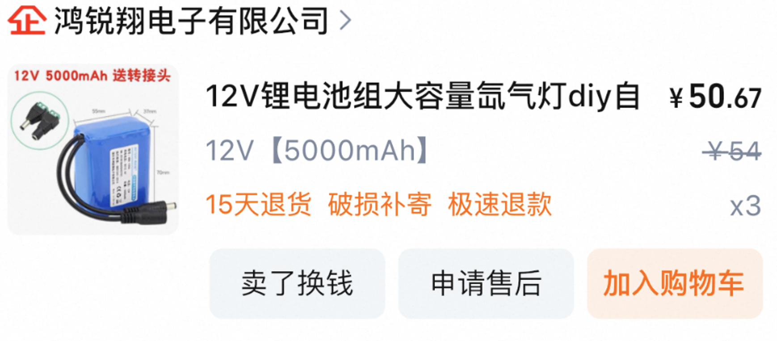
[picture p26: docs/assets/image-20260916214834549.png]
12 V 锂电池（图1）


#### 10. 侧边装饰压条

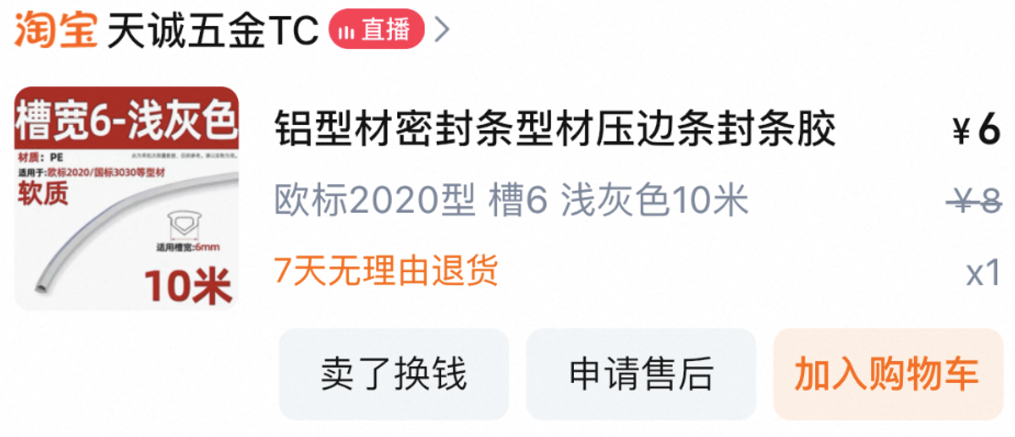
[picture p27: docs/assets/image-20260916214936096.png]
侧边装饰压条（图1）


#### 11. 直线轴承

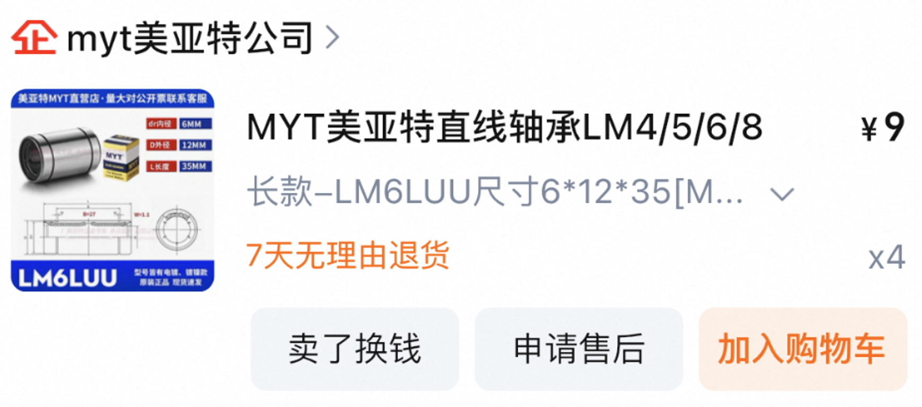
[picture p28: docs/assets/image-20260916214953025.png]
直线轴承（图1）


#### 12. 带齿轮与惰轮选型参考

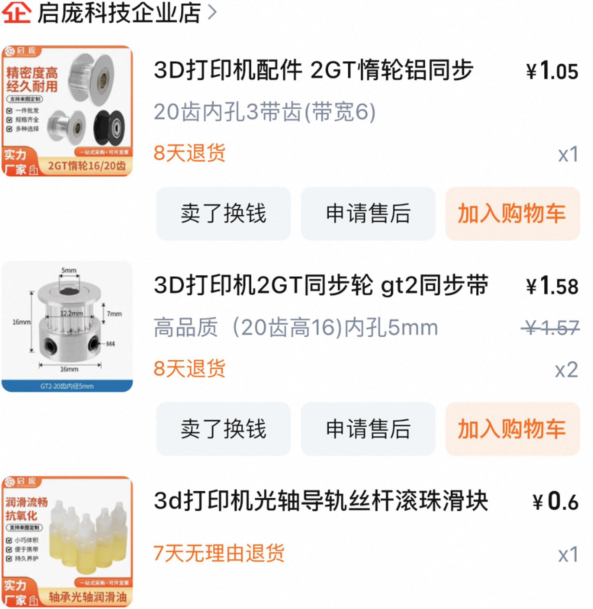
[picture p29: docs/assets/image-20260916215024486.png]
带齿轮与惰轮选型参考（图1）


#### 13. 摄像头，最终镜头参数待确认

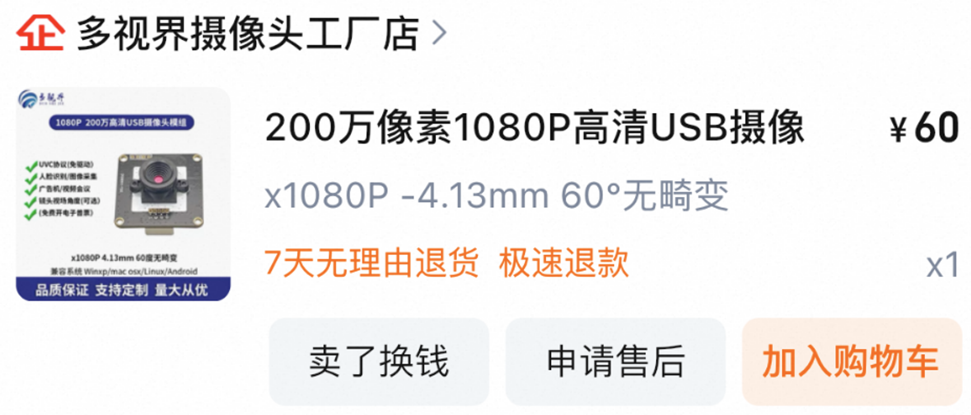
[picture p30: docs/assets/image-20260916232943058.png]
摄像头，最终镜头参数待确认（图1）


#### 14. 二维云台俯仰连接件

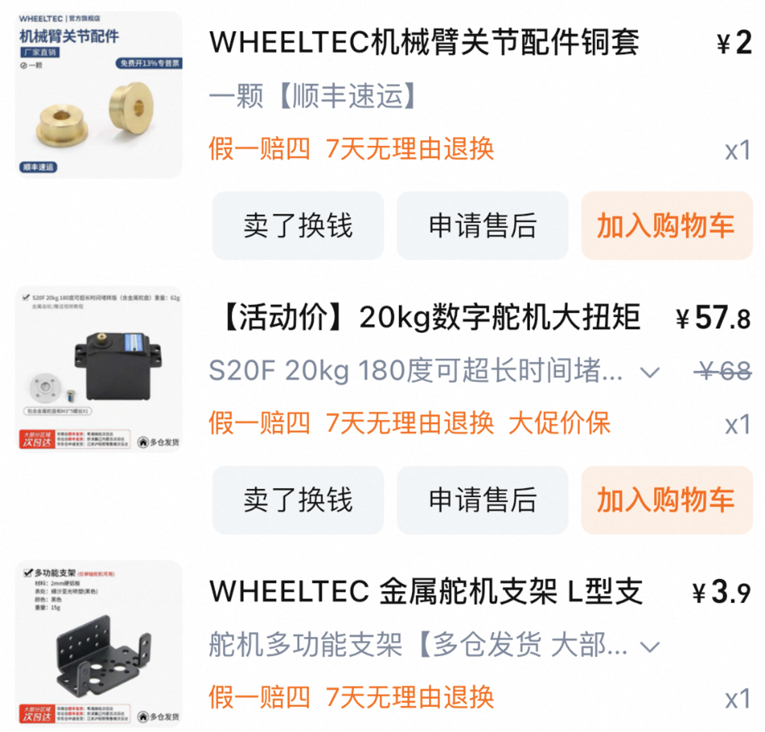
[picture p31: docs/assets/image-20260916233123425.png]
二维云台俯仰连接件（图1）


#### 15. 上下走线方管

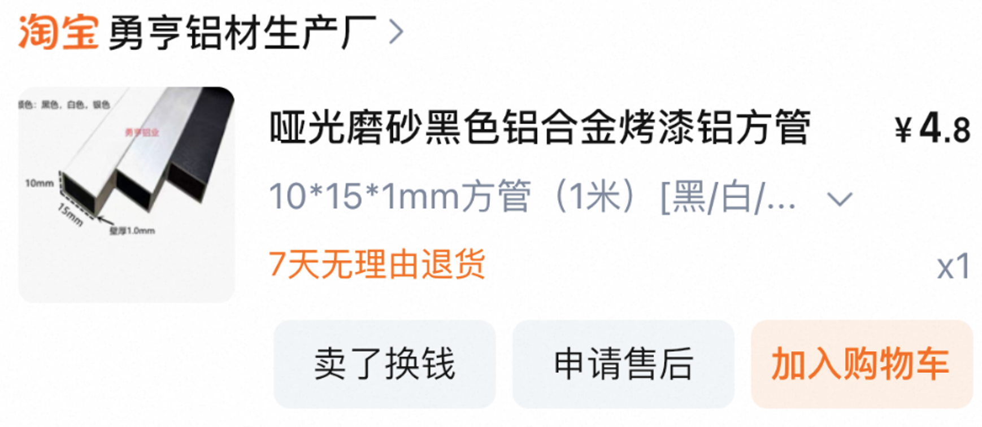
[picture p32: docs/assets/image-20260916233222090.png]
上下走线方管（图1）


#### 16. 螺丝与螺母

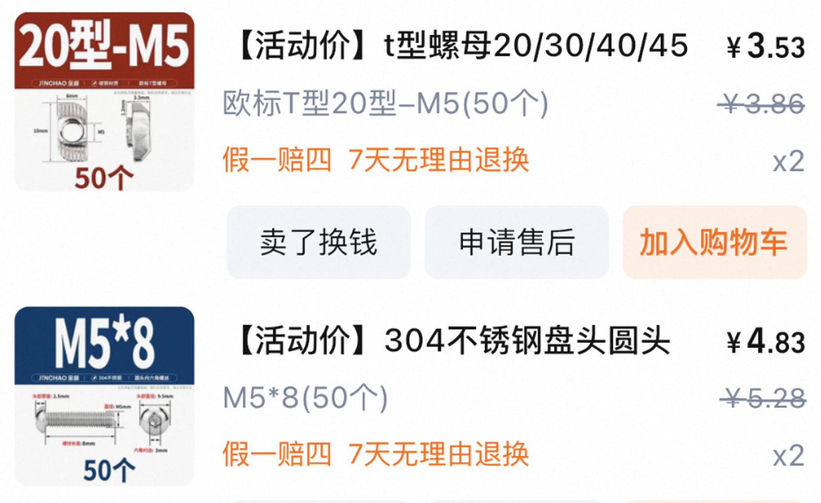
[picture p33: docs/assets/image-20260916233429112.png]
螺丝与螺母（图1）


#### 17. 上下两组 DC 电源模块

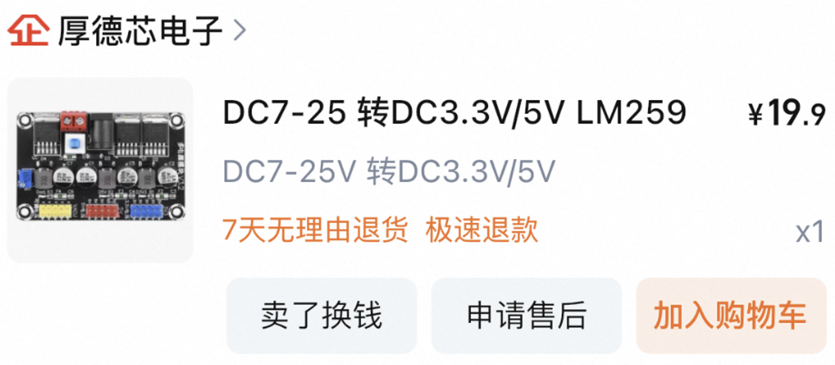
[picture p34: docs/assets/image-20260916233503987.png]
上下两组 DC 电源模块（图1）


#### 18. 显示连接线

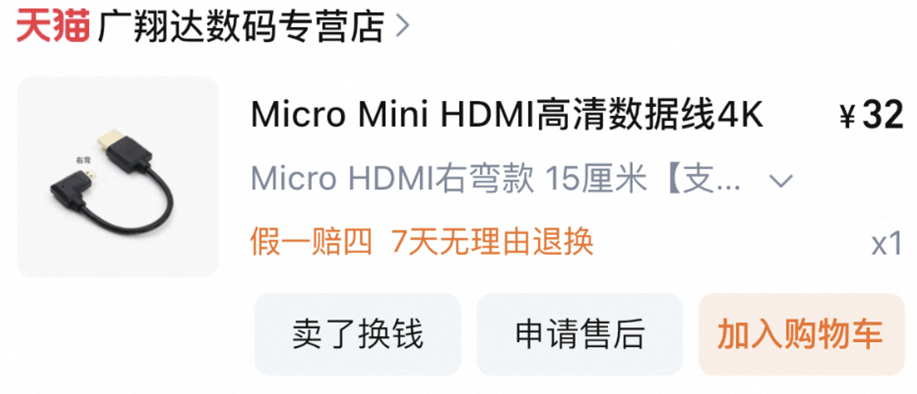
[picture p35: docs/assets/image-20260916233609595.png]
显示连接线（图1）


#### 19. 可插拔线材接口

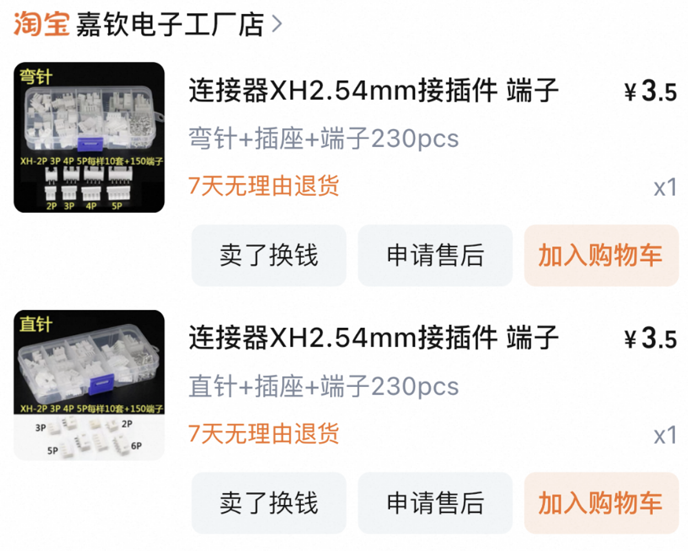
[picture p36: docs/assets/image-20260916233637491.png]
可插拔线材接口（图1）


#### 20. 电动推杆，可省略

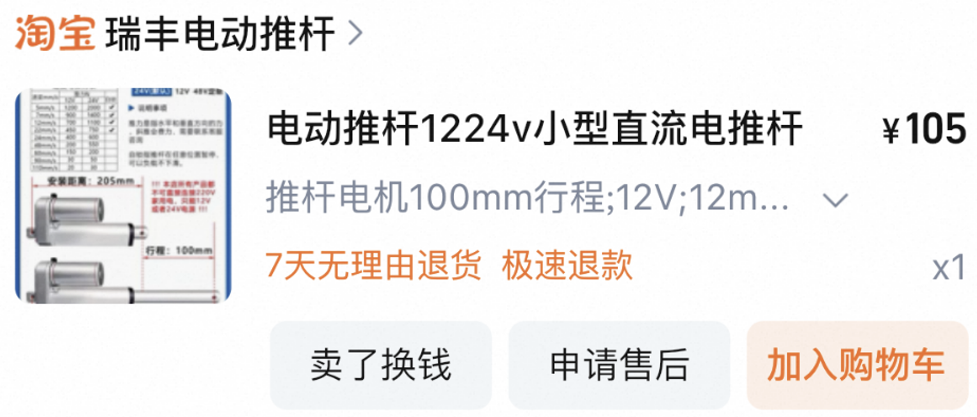
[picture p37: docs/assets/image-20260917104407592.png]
电动推杆，可省略（图1）


#### 21. 超声波传感器

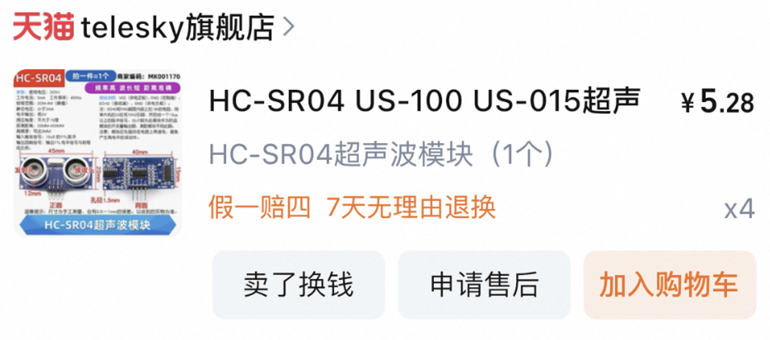
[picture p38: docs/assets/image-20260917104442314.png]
超声波传感器（图1）


#### 22. 补光灯，另需 Arduino 控制板

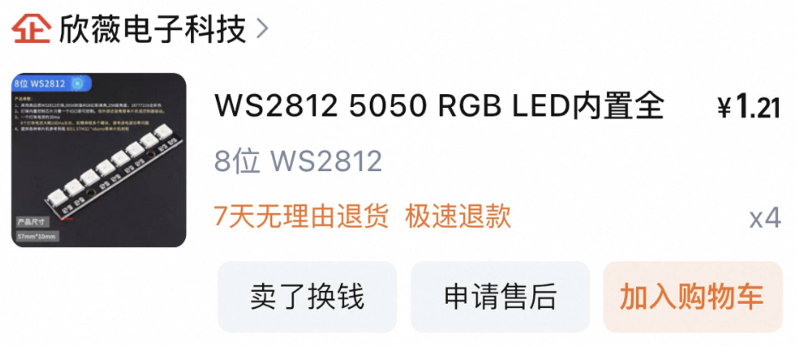
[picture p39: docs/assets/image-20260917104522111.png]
补光灯，另需 Arduino 控制板（图1）


#### 23. 黑色托盘覆盖件耗材

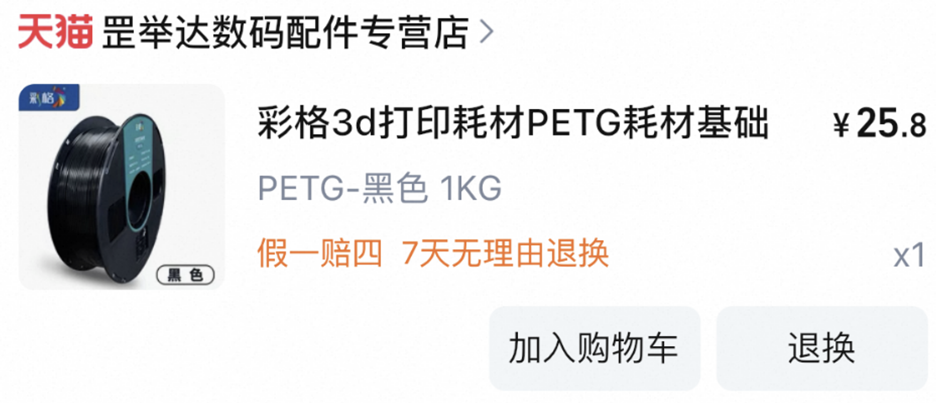
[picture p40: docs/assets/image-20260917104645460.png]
黑色托盘覆盖件耗材（图1）


#### 24. 亚克力板

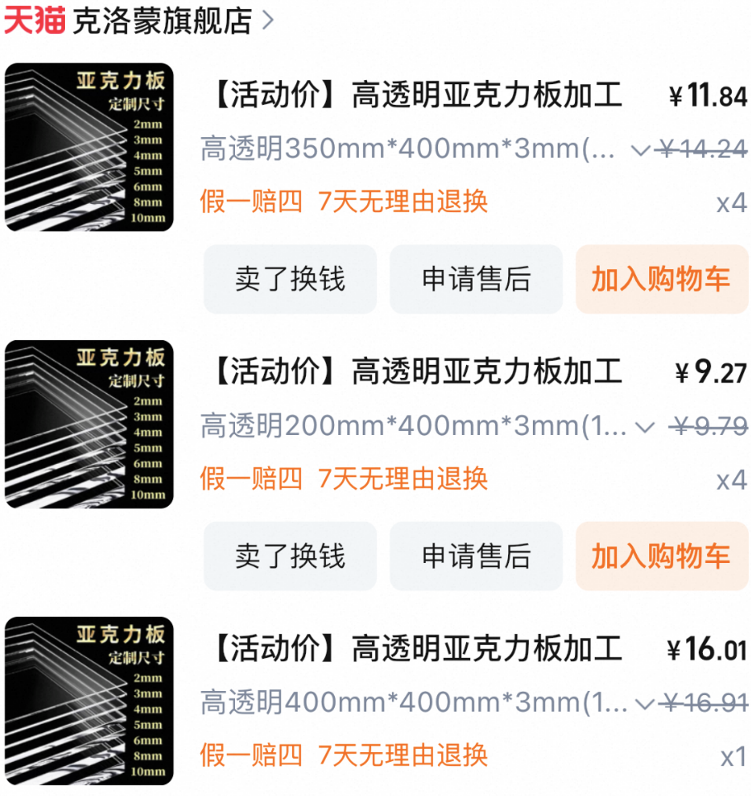
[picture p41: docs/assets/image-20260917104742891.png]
亚克力板（图1）


#### 25. 外观装饰材料

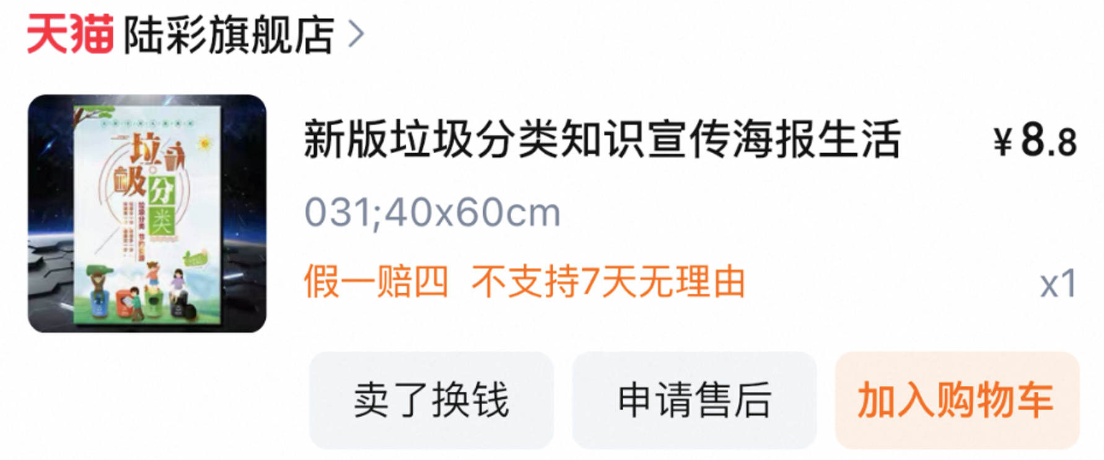
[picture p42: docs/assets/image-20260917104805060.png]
外观装饰材料（图1）


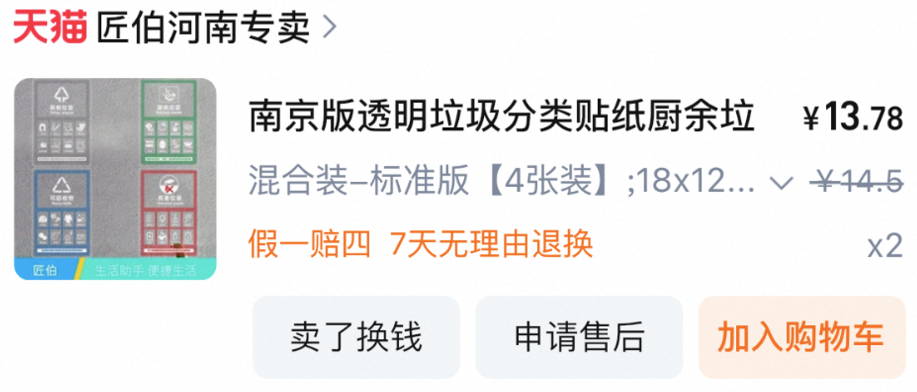
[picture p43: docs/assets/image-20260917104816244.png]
外观装饰材料（图2）


## 机械装配过程

整个装置采用从上到下的安装顺序。顶部空间留给摄像头、CoreXY 和机械爪，中部安装托盘与挡板，底部安装四个收集桶。先把框架和运动机构装顺，再固定电池、电源及外壳，避免装好外设后又要拆开返工。

### 1. 确定尺寸并搭建铝型材框架

#### 1.1 先区分整机外尺寸、框架尺寸和型材长度

本机的设计尺寸目标是宽 400 mm、深 400 mm、高 600 mm。绘图时要将外壳算在整机尺寸里：如果左右两侧各覆盖 3 mm 厚的板材，框架在这个方向的外尺寸就应控制在 `400 − 3 − 3 = 394 mm`。并非所有方向都减同样的数值，具体取决于顶板、底板和侧板覆盖在哪里。

2020 型材的截面宽度是 20 mm。假设某横梁夹在两根立柱之间，其切割长度还需要从框架外宽中减去两侧立柱所占尺寸；若采用另一种搭接方式，则需要重新计算。**下单给商家的应是每根型材的切割长度，而不是整机宽度。**

保持 400 × 400 × 600 mm 这一级别的布局，有利于沿用现有托盘和挡板结构。若明显改变宽深、高度或摄像头位置，应一起检查托盘尺寸、挡板连接臂、CoreXY 行程和镜头覆盖范围。

#### 1.2 整理型材及连接件

框架使用 2020 欧标铝型材，主要分为三组：

| 分组 | 数量 | 位置 |
| --- | --- | --- |
| A | 4 根 | 四根竖直立柱 |
| B | 14 根 | 上下边框共 8 根、顶部中间横梁 1 根、底部中梁 1 根、四个侧面各 1 根横梁 |
| C | 2 根 | 分别接在底部中梁两侧，组成四分区支撑 |

B 组表示相同用途的一组横梁，实际能否全部等长取决于连接方式。先完成装配尺寸图，再确认各组长度。底部十字结构用于支撑云台和划分四个桶位，不需要用型材把每个桶围成独立框架。

连接件包括 2020 型材角码、配套螺栓、槽用螺母，以及固定打印件的螺丝。需要从型材端部滑入的螺母，要在封闭框架前放进去；可以从槽口装入的型号，也要核对槽宽是否匹配。

#### 1.3 实际安装顺序

1. 在平面上拼好底部边框，螺栓先拧到能保持位置，不立即完全锁死。
2. 安装四根立柱，再连接顶部四根横梁，形成长方体。
3. 测量上下框的对角线，调整框架方正，确认放在台面上不会翘角。
4. 安装底部中梁和两根分隔梁，预留中心云台安装位置。
5. 放入各侧需要使用的槽用螺母，安装四个侧面横梁。
6. 顶部中梁及屏幕附近的横梁先保留可拆卸状态，后面还要装投入口、屏幕固定件和摄像头。
7. 主要组件试装后，再统一锁紧并复测尺寸。

图中的框架照片用于说明型材位置，不同颜色或早期支架不影响这一步的型材布局。完成后应能清楚看到顶部安装区、中部托盘区和底部四个收集区。

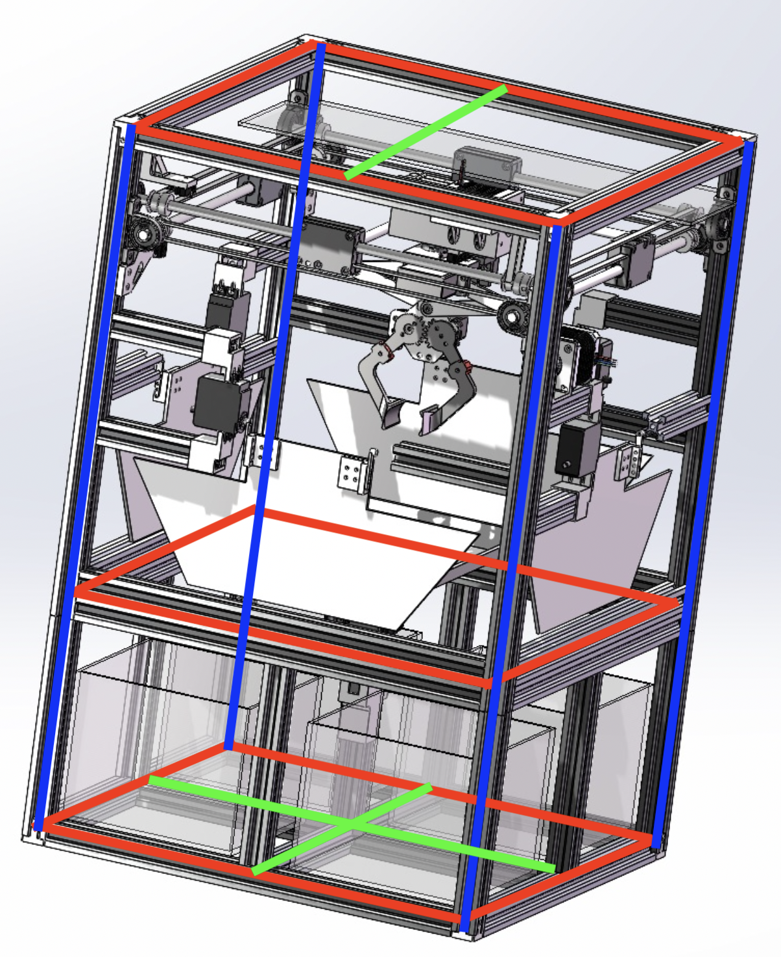
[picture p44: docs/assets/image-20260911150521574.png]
1. 搭建铝型材框架（图1）


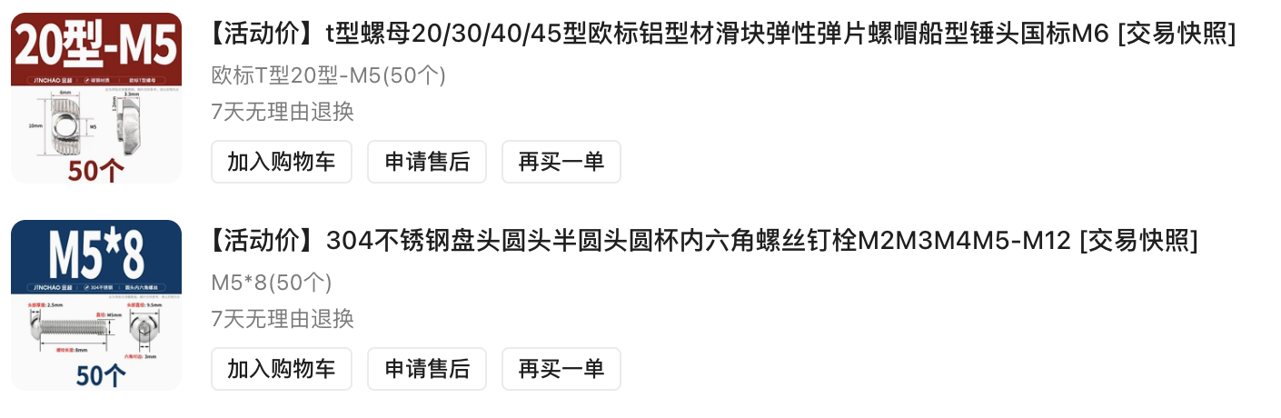
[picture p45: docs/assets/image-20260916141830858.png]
1. 搭建铝型材框架（图2）


### 2. 安装投入口及红外光幕

#### 2.1 检查投入口模型

投入口模型为 `hardware/mechanical/投入口.SLDPRT`。这个模型在比赛实践环节中调整过，所以打印前应先检查当前尺寸，确认上下卡槽、开口及四角安装孔与自己的框架匹配。

正对投入口时，上端连接顶部中间横梁，下端连接正面的支撑位置。先量出两处型材之间的净距离，再检查打印件能否放入。左右宽度不仅要容纳垃圾，还要给红外光幕的发射端、接收端及固定螺丝留空间。

如果需要重建模型，可先画投入口外框和开口，再设置上下与型材连接的部分，最后按光幕实物孔距增加固定孔。不要先把打印件做满两根型材之间的理论尺寸，再依靠强行挤压安装。

#### 2.2 将光幕固定在开口下方

红外光幕位于投入口下方，发射端与接收端相对安装。物体穿过开口后遮挡光束，STM32 据此判断发生了投料。

先把光幕固定到打印件上，检查两端高度和朝向一致，再将整个投入口装入框架。这里采用上下卡入型材的结构，先装投入口、后固定横梁会更容易。四角螺丝锁紧时不要把支架拉歪，否则可能导致部分光束无法正常对准。

线束从固定侧引出，贴着框架走线。不要让线束穿过投入口，也不要把接头藏在以后必须大拆框架才能拔出的位置。

#### 2.3 对应的电气与软件行为

省赛程序从 **PB13** 读取光幕信号，配置为上拉输入，读取到低电平时触发。购买的光幕必须确认输出形式与该逻辑匹配；供电线、信号线不能只凭颜色辨认。若模块输出电平与控制板不兼容，需要匹配的接口电路。

调试时先不让机械结构动作，只观察 PB13 在无遮挡和遮挡时的状态。用不同大小物体从左、中、右位置通过，确认信号都能变化。光幕检测到“有物体经过”，并不等于知道物体个数，因此后续数量和类别由视觉程序判断。

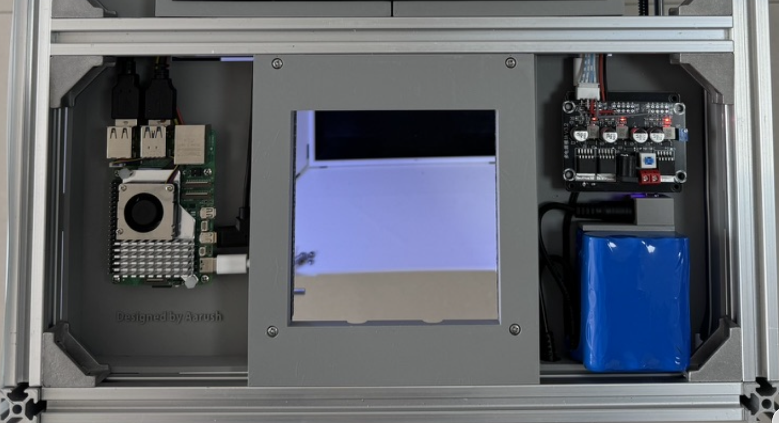
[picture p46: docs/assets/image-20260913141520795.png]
2. 安装投入口与红外光幕（图1）


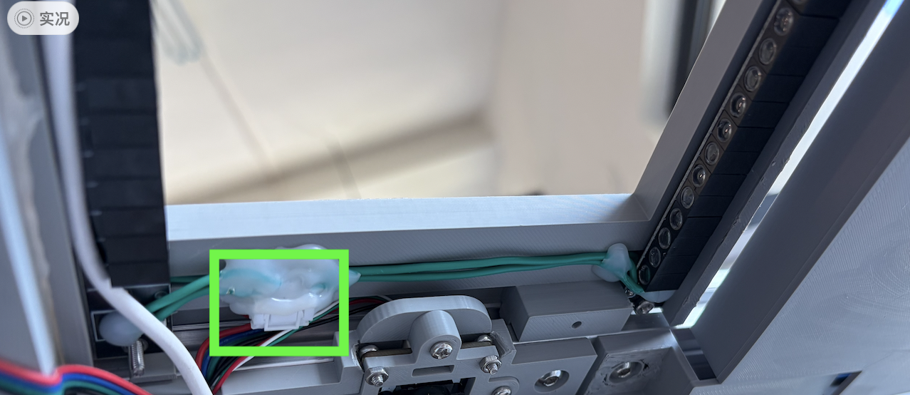
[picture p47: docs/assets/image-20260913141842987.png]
2. 安装投入口与红外光幕（图2）


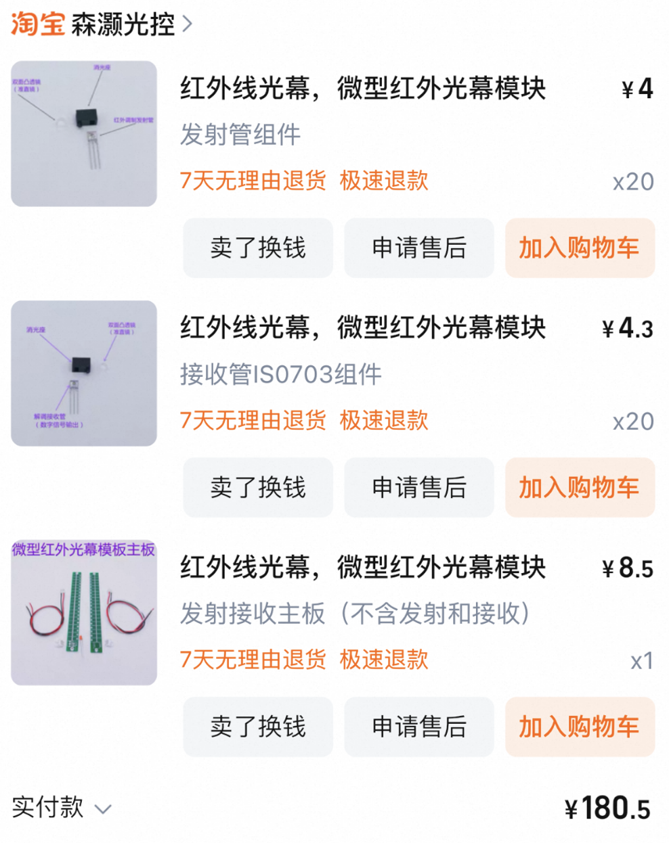
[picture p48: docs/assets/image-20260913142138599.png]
2. 安装投入口与红外光幕（图3）


### 3. 安装显示屏并划分前部设备区

#### 3.1 理清正面空间

装置正面的横梁将安装区分成上下两部分。上部用于屏幕、屏幕驱动板、STM32 和接线；下部中间为投入口，左侧安排树莓派，右侧安排电池及电源模块。

此时先装屏幕及固定支架，树莓派、电池和电源可等 CoreXY 装好后再固定。这样能保留操作空间，方便拧紧内部螺丝和调整皮带。

#### 3.2 屏幕固定件安装

`hardware/mechanical/显示屏固定.SLDPRT` 需要打印两件，拼接后固定屏幕。使用前测量屏幕外框厚度、显示区域、驱动板位置和线缆插头方向。实验室使用的屏幕没有完整型号记录，更换屏幕后通常需要调整固定件。

安装时先拆下顶部阻挡打印件滑入的一根横梁，将固定件及屏幕试放进去，确认没有压住显示区域和排线，再装回横梁。不要依赖屏幕玻璃承受框架夹紧力，支撑应落在合适的外框或固定位置。

驱动板放在屏幕后侧的预留区域，固定前加绝缘支撑，避免电路板背面焊点接触金属型材。HDMI、USB 和电源插头周围保留拔插空间。

#### 3.3 屏幕接口与界面尺寸

本机屏幕使用 HDMI 显示、USB 触控及 12 V 供电，可选带扬声器。树莓派和屏幕之间的显示线应按两端实际接口购买，触摸功能另接 USB 线，不能只插显示线就期待触控工作。

省赛 `qml/main.qml` 的界面按 **1280 × 800** 固定尺寸设计，并以全屏方式打开。换成其他分辨率的屏幕后，需要检查布局、按钮和字体是否完整显示。

先单独点亮屏幕、验证触控，再进入后续安装。屏幕和驱动板固定后，确认螺丝及线头不会伸入 CoreXY 运动区域。

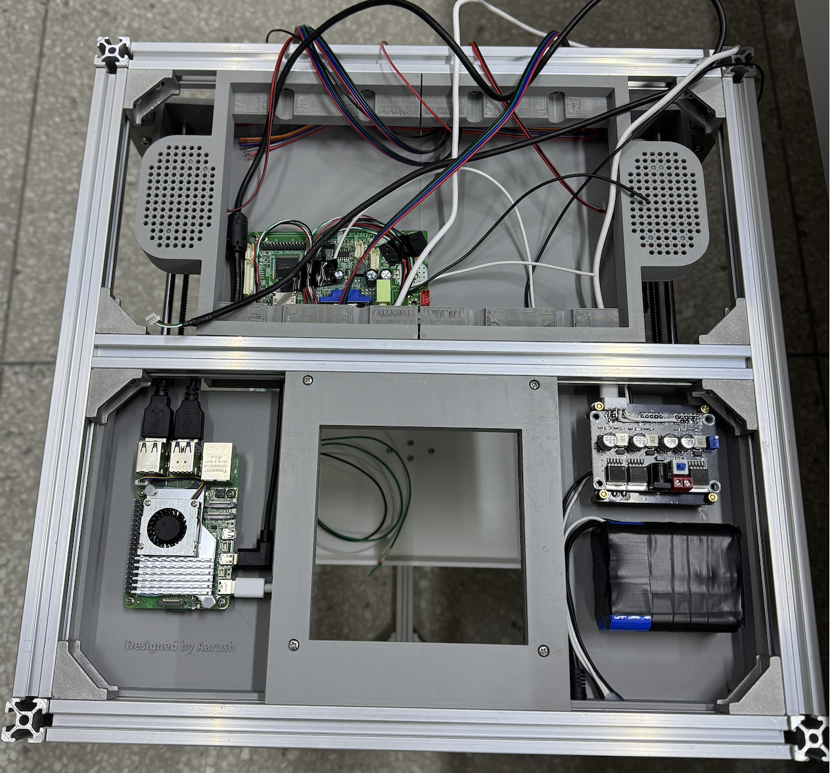
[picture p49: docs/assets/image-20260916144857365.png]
3. 安装屏幕与预留控制区（图1）


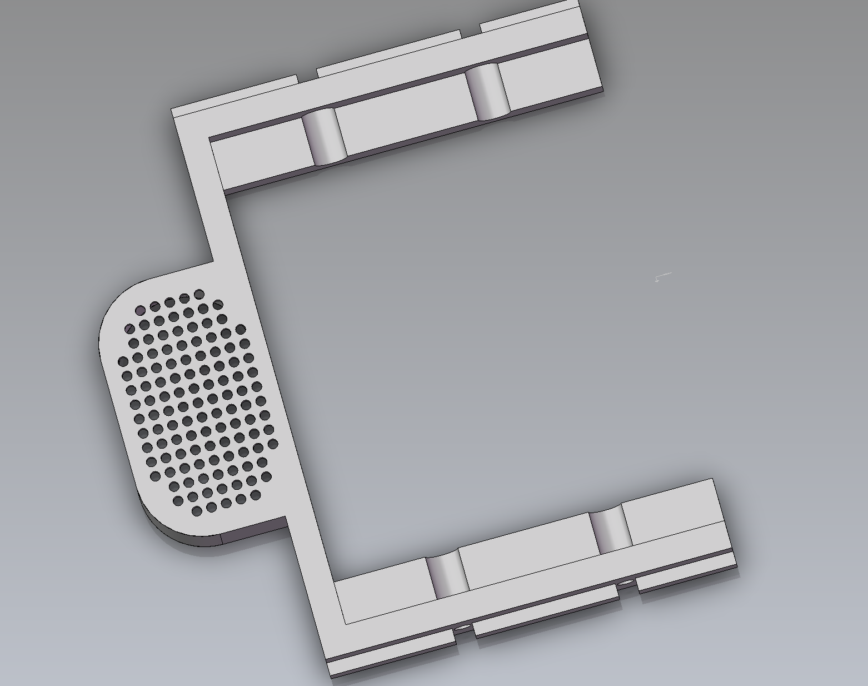
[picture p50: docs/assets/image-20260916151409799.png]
3. 安装屏幕与预留控制区（图2）


### 4. 安装摄像头并确定托盘拍摄范围

#### 4.1 安装摄像头支架

摄像头使用 `hardware/mechanical/摄像头.SLDPRT` 和 `hardware/mechanical/摄像头盖.SLDPRT` 两个打印件固定。先将摄像头放入支架，确认镜头不被遮挡，连接线能够自然引出，再装盖板。

整套支架安装在顶部中间横梁下方，镜头朝下。尽量让摄像头位于托盘上方的中间位置，而不是在偏向一侧的位置斜着拍摄。先保留支架微调余量，等托盘高度确定后，再调整拍摄范围并锁紧。

#### 4.2 选择镜头和安装高度

这个项目早期使用过约 60° 的镜头，后续更换过，最终视场角暂未确认。复刻时不要把不确定的 85° 当作固定采购参数。

在框架内先用纸板模拟托盘的轮廓和高度，打开实时画面，检查四个角是否完整进入画面。如果拍不全，应调整安装高度或镜头；如果画面包含大量托盘之外的区域，目标在图像里会变小，可重新选择覆盖范围。

理想状态是整个托盘都在画面中，边缘保留少量余量，且目标放在四角时仍然清晰。购买镜头时要区分商家给出的水平、垂直或对角视场角，最终以实拍检查为准。

#### 4.3 与机械爪共同检查空间

摄像头占据横梁下方的一部分空间，CoreXY 中心滑台经过这里时不能碰到摄像头支架、镜头和线缆。因此，摄像头不是装好后就完全不用再管：安装平台时要再次检查它的下方净空。

固定线束后，手动让中心滑台走过完整工作区，尤其检查滑台带着旋转舵机和接线板后的最高点。通过检查后再给平台通电。

更换镜头、分辨率、图像方向、摄像头位置或托盘高度后，需要重新进行像素坐标到机械坐标的标定。不能只让新画面“看起来差不多”，就继续使用旧系数。

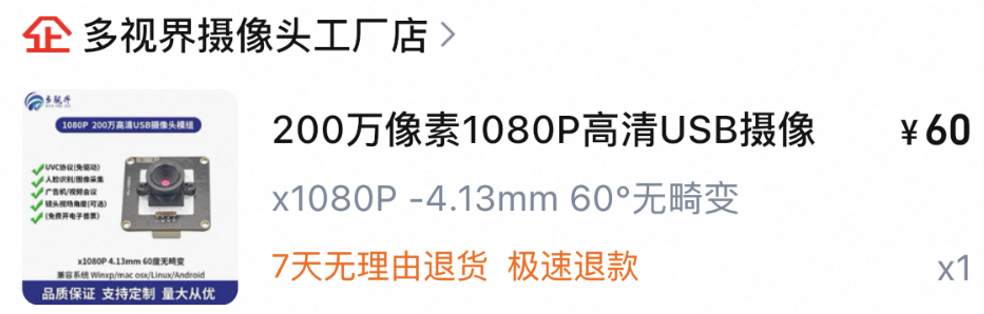
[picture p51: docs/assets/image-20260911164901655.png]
4. 安装摄像头（图1）


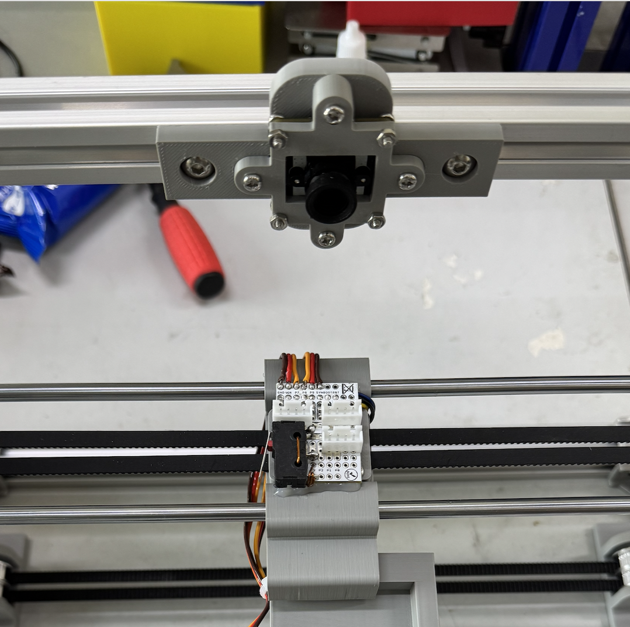
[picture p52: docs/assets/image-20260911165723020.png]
4. 安装摄像头（图2）


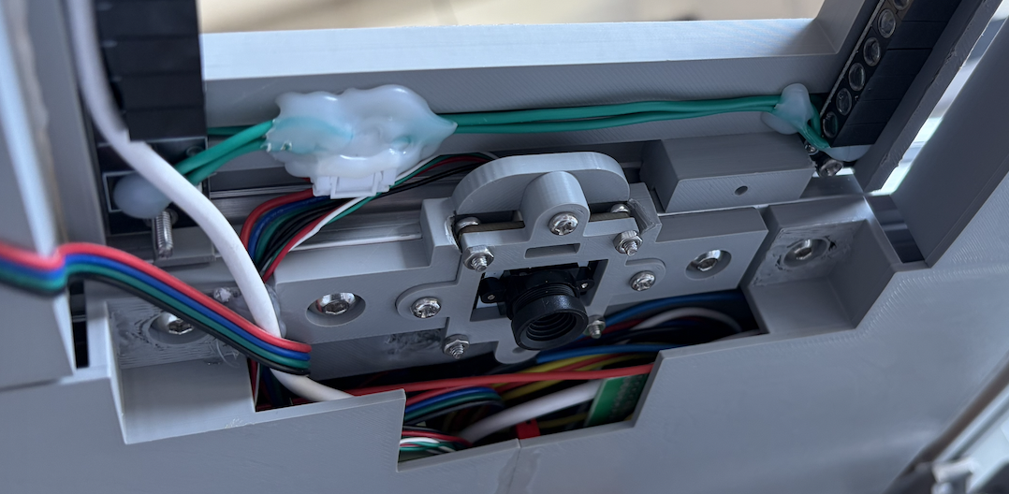
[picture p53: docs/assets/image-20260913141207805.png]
4. 安装摄像头（图3）


### 5. 装配 CoreXY 平台、同步带与回零机构

#### 5.1 准备模型和传动零件

平台零件主要位于 `hardware/mechanical/XY平台/`。`Woodcore XY-CORE by Rics_3D - 2555558` 是参考设计资料（完整参考包在本地归档，见 `references/README.md`），照片中的结构可用于理解传动布局；打印与装配时应以本项目使用的零件组合为准。

需要两套步进电机及驱动器、6 mm 光杆、匹配的直线轴承、两条同步带、带齿轮和无齿惰轮，以及滑轨支架、滑台和电机支架等打印件。直线轴承的最终型号需同时核对内径、外径和长度，不能只确认模型安装孔约为 12 mm 就下单。

带齿轮按两类分别准备：第一类使用 6 个，第二类使用 2 个；无齿惰轮使用 4 个。可适量准备备件，但先核对齿距、带宽、轴孔及轮的有效宽度。采购图中的数量不作为装配数量依据。

#### 5.2 安装光杆、支架和滑台

先按模型确定光杆的实际长度，再切割并处理两端毛刺。把轴承装入对应滑块后，先在单根光杆上试滑，确认没有明显卡点，再装入框架。

两侧导向安装时保持平行，不要一边把支架锁死，另一边再靠用力掰正。可以先略微松开固定螺丝，让滑块沿行程移动，再逐步锁紧。若某一段明显变紧，检查光杆平行度、打印孔位和支架受力，不能依靠加大电机力矩硬拖过去。

安装中心滑台后，检查它在各方向的移动空间。这里的中心滑台也承担旋转舵机、夹爪和移动接线板，装好夹爪后的重量和外形都会增加，所以要保留结构余量。

#### 5.3 穿入两条同步带

`XY平台/Riemenklammer.stl` 需要打印两个，用于夹紧同步带端部。先把两条皮带的一端固定到中心滑台，再分别按照各自路径穿过电机轮和转向轮，最后将另一端固定回滑台。

检查时分开追踪每一条皮带，不要把两条带当作一条绕。逐段确认：这段带属于哪一层、接触轮子的齿面还是背面、经过转向后是否与另一条带摩擦。夹紧端部时，应确认皮带不会从固定件中慢慢滑出。

穿带完成后逐步收紧两条皮带，使其有稳定张力，同时仍能平顺推动滑台。不要把皮带拉到支架明显变形；张力过大也可能让轴承受力偏斜。先手动跑完全程，确认皮带不爬边、不脱槽、不磨打印件，再安装电机控制线。

现有照片没有完整展示每一段带路。实际穿带应结合模型和参考结构逐段追踪，不凭一张局部照片推测被遮住的路径。

#### 5.4 调整整个平台的高度

电机支架不必紧贴顶框安装。平台需要向下留出距离，保证中心滑台、旋转舵机及接线板经过摄像头下方时不发生碰撞。

先完成摄像头位置和滑台试装，再上下调整平台支架。高度越低，托盘上方的抓取空间越小，因此要在“避开摄像头”和“给夹爪留下伸缩行程”之间协调，而不是直接照照片估算一个高度。

#### 5.5 安装两个限位开关

限位开关分别安装在固定支架和中心滑台附近，用于判断滑台是否到达回零角落。固定开关前，手动把滑台移到目标位置，确认触发的是开关拨杆而不是直接撞击开关本体；到位后应仍有少量机械余量。

回零由步进驱动器完成，省赛 STM32 程序没有为这两个开关定义独立输入引脚。开关应接到执行回零的驱动器限位接口，具体端子和有效电平要按所用驱动器版本确认。

若使用两个常开触点串联，只有两个触点同时闭合，通路才闭合；驱动器能否将此解释为到位，还取决于输入逻辑。不能把两个常闭触点串联后认为逻辑与前者相同。

#### 5.6 配置延时上电回零

本机采用一台电机先回零、另一台电机通过继电器延时供电的方式。先上电的驱动器开启“上电回零”，并设置匹配的方向、限位条件和速度；后上电的驱动器不执行自己的上电回零。

回零阶段，后上电电机不主动保持位置，转子可被皮带带动。先上电电机带动机构向初始角落运动，限位条件满足后停止。由于这种做法依赖具体传动和限位布置，首次调试必须降低速度并检查完整路径。

STM32 用 **PB6** 输出继电器控制信号：初始化为高电平，约 15 秒后变为低电平。只有当继电器接法与这个电平变化相匹配时，才能实现第二台电机的延时上电。先不接电机负载，验证继电器在上电和 15 秒后的状态，再连接驱动器电源。

这里没有从驱动器返回给 STM32 的“回零完成”反馈，程序只等待固定时间。因此机械回零必须在延时结束前完成；卡住或限位失效时，STM32 并不知道实际没有回到原点。

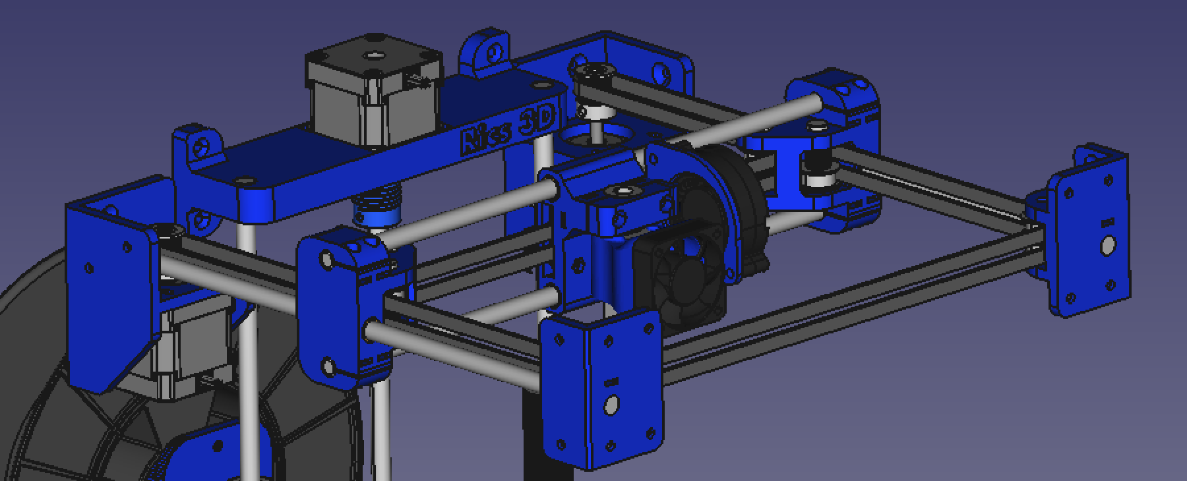
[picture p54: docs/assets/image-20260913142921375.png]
5. 装配 CoreXY 平台与回零机构（图1）


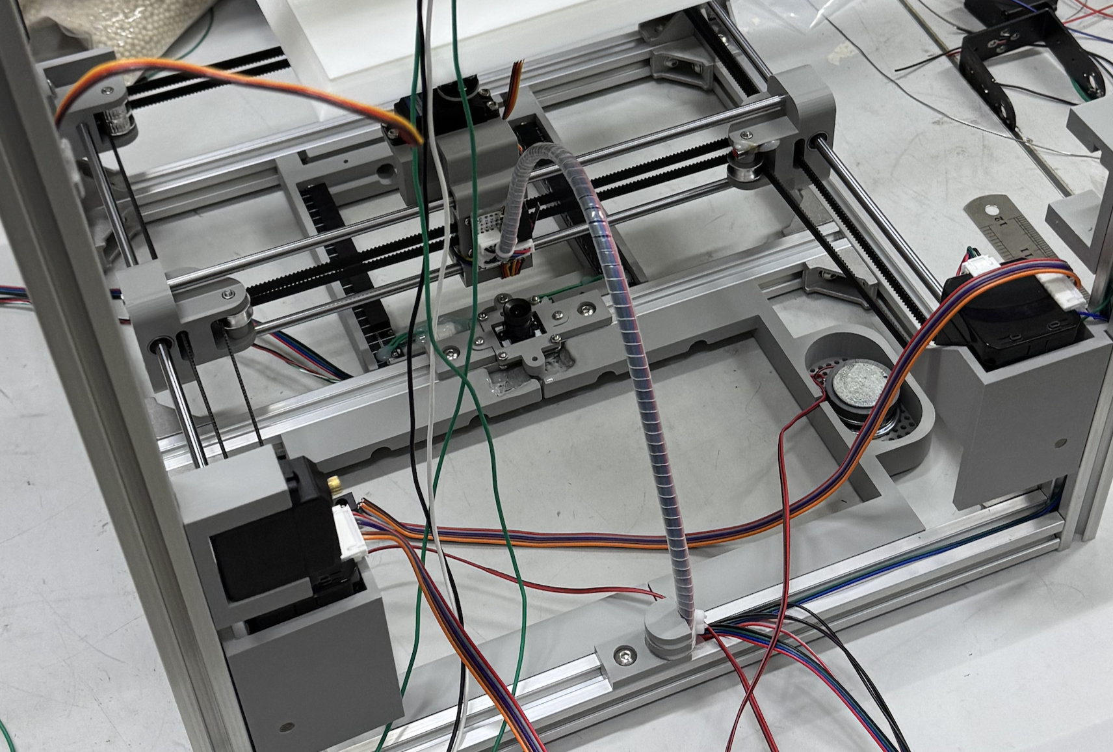
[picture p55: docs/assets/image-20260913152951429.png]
5. 装配 CoreXY 平台与回零机构（图2）


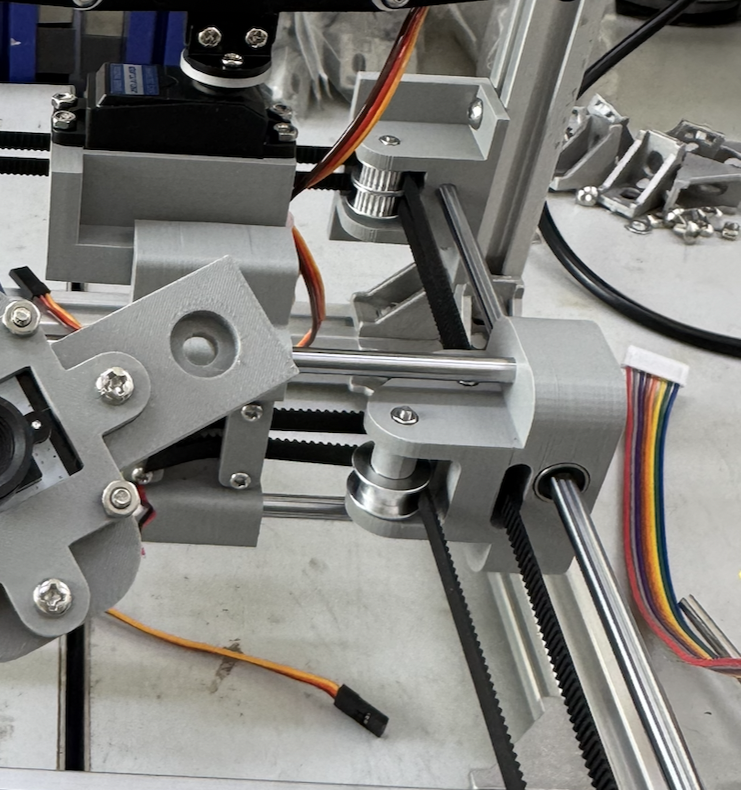
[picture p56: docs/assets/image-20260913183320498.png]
5. 装配 CoreXY 平台与回零机构（图3）


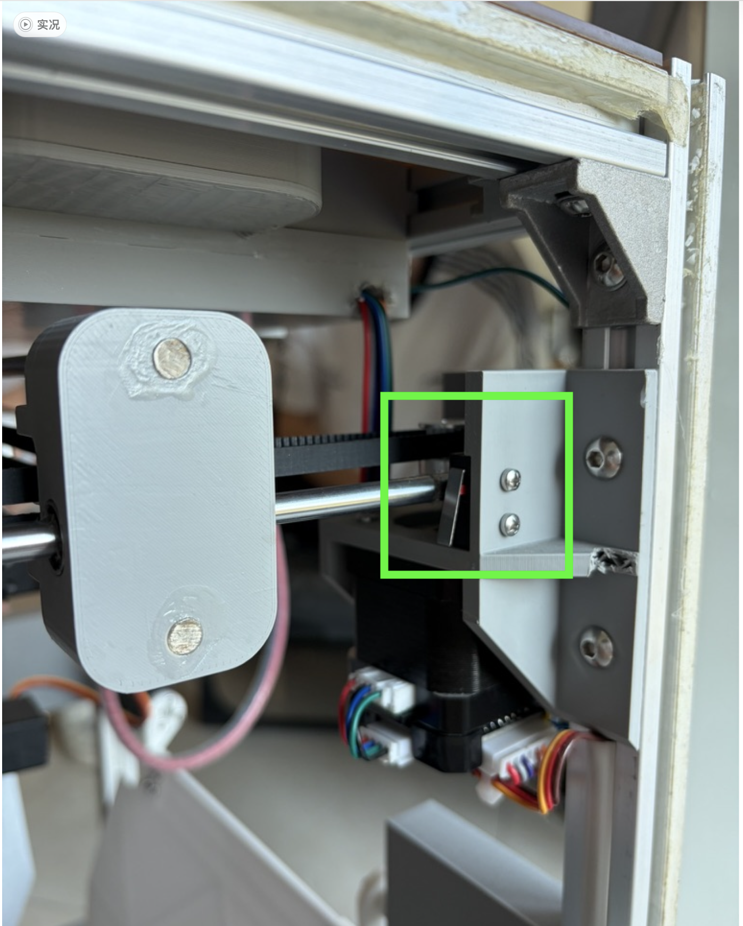
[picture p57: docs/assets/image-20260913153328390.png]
5. 装配 CoreXY 平台与回零机构（图4）


5. 装配 CoreXY 平台与回零机构（图5）

5. 装配 CoreXY 平台与回零机构（图6）

5. 装配 CoreXY 平台与回零机构（图7）

5. 装配 CoreXY 平台与回零机构（图8）

5. 装配 CoreXY 平台与回零机构（图9）

5. 装配 CoreXY 平台与回零机构（图10）

5. 装配 CoreXY 平台与回零机构（图11）

5. 装配 CoreXY 平台与回零机构（图12）

### 6. 组装四舵机机械爪并整理移动线束

#### 6.1 分清四个舵机

机械爪包含旋转舵机 1 个、伸缩舵机 2 个、开合舵机 1 个。旋转舵机直接安装在 CoreXY 中心滑台，下面连接伸缩支架，末端连接夹爪。支架与装配参考主要位于 `hardware/mechanical/垃圾桶/`，末端夹爪可使用配套购买的金属结构。

先把四个舵机贴上“旋转、夹爪、伸缩 A、伸缩 B”标签，避免接线和调试时认错。两个伸缩舵机需要机械配合，不能因为都有 PWM 信号就认为安装方向一定正确。

#### 6.2 舵盘安装前先设定角度

将舵机接入控制器，在不带负载时给出明确的参考角度，再装舵盘与连杆。90° 可用作初步装配参考，但完整程序的初始角度不是全部 90°：旋转为 85°、夹爪为 40°、伸缩为 70°。

推荐先用 90° 检查舵机能否稳定定位，再结合上述程序初始值确定舵盘安装方向。固定舵盘前确认连杆处于预期姿态，固定过程中不要手动拧动输出轴。若花键齿位无法正好对齐，微调程序角度，而不是强行扭住舵机安装。

机械爪运行时使用的下降、抓紧、抬升和张开角度，还要在实物上逐项校准。所谓“夹紧 105°”只是舵机的控制目标，不代表夹爪一定以某个固定力夹住所有物体。

#### 6.3 组装伸缩结构

先装旋转舵机和上部支架，再安装两个伸缩舵机及两侧连杆，最后连接下部夹爪。所有转动连接应检查能否自由活动，螺丝不能把连杆夹到转不动，也不能松到存在明显侧向晃动。

两个伸缩舵机由程序输出相同角度，分别使用 PB0、PB1。安装时需要让两侧结构在相同指令下共同向下或共同抬起。如果一侧下压、另一侧上提，先检查舵盘和连杆方向，不能长时间通电让两个舵机互相顶住。

先试一个很小的伸缩范围，确认动作协调，再逐步接近工作高度。夹爪下降到托盘附近时，需要保留不会撞击托盘的余量，并考虑目标自身高度。

#### 6.4 制作移动接线板

中心滑台上的接线板用于汇集四个舵机和限位开关线束，便于拆装。四个舵机各有电源、地和信号；在板上进行合适的电源分配后，对外可保留共享电源正负两根、四路信号以及限位触点两根线。

接线板采用 3 个 4 pin 可插拔接头时有 12 个针位，不代表必须使用全部针位。先画清针脚分配并贴标签，再焊接。是否共用一对供电针脚，需要按电流、线径和接头额定能力确定，不能只为了减少线数而把电流集中到过小的接点。

接线板装在中心滑台上，同步带紧固件位于相邻位置。应先确认皮带固定可靠、滑台运动顺畅，再安装接线板。板背焊点做绝缘处理后固定，线束出口做应力释放，避免移动过程中靠焊点承受拉力。

#### 6.5 为移动线束留出行程

先将滑台移动到离固定线束出口最远的位置，再确定线束长度；接着移到最近的位置，检查多余线束是否会掉入皮带和夹爪。最后依次检查四角和中间位置。

图中的理线打印件用于约束线束走向。它应引导线束弯曲，而不是把线束绷紧。所有动作检查完成后再扎紧，保留拆卸夹爪和接线板所需的插拔空间。

6. 安装机械爪与移动线束（图1）

6. 安装机械爪与移动线束（图2）

6. 安装机械爪与移动线束（图3）

6. 安装机械爪与移动线束（图4）

### 7. 制作带轴承支撑的二维云台

#### 7.1 为什么增加轴承

托盘既要承接从投入口落下的物体，又要旋转和倾倒。若整个托盘仅靠舵机输出轴和一个薄连接点支撑，落物冲击容易让机构晃动。这里给水平旋转部分增加独立轴承支撑，舵机负责驱动，支撑结构共同承担机械载荷。

所需主要打印件为 `底部舵机固定.SLDPRT`、`轴承舵机连接件.SLDPRT`、`轴承紧固.SLDPRT` 和 `旋转托盘.SLDPRT`，轴承型号为 6810ZZ。

#### 7.2 先安装底部水平舵机

将底部舵机放进 `底部舵机固定`，先检查固定耳、线束出口和螺丝空间。这个底座下方的圆弧用于避让压缩杆；不安装压缩杆时，可以修改该区域增加支撑面积，但不要封住舵机走线和固定孔。

舵机连接 PA0 对应的水平 PWM。设置到 90° 后，再固定舵盘；程序将这个位置作为托盘水平旋转的中间位置。舵盘使用舵机配套的小圆盘，安装时核对花键规格与固定螺丝。

#### 7.3 安装轴承和旋转连接件

先用舵盘连接 `轴承舵机连接件`，再将 6810ZZ 轴承放入设计槽位。核对哪一部分是固定支撑、哪一部分随托盘转动，避免用压盖同时锁住应转动的部分。

安装 `轴承紧固` 后，检查轴承是否被可靠限位，同时旋转部件仍可顺畅运动。若压盖拧紧后明显变涩，检查打印尺寸、轴承是否歪斜、螺丝是否让打印件变形。

最后安装 `旋转托盘`，将其与上部俯仰舵机和铝合金连接件组成完整云台。此时先不装大托盘，单独检查水平旋转和俯仰动作。

#### 7.4 安装俯仰机构并检查角度

俯仰舵机接 PA1。省赛程序的托盘复位角度为水平 90°、俯仰 94°，所以不能只根据机械上“看起来水平”就把程序的 94°改成 90°，应先校准舵盘安装关系。

完整倾倒动作会将水平转至 45°或 135°，俯仰转至 48°或 140°。先在没有垃圾的情况下逐渐测试这些位置，检查支架与框架是否干涉，再安装托盘并承载试验。

若改用现成的带支撑云台，可以省去部分打印装配，但需要重新检查高度、孔距、负载和活动范围，现有托盘接口及角度参数也可能要调整。

7. 安装带轴承支撑的二维云台（图1）

7. 安装带轴承支撑的二维云台（图2）

7. 安装带轴承支撑的二维云台（图3）

7. 安装带轴承支撑的二维云台（图4）

7. 安装带轴承支撑的二维云台（图5）

7. 安装带轴承支撑的二维云台（图6）

### 8. 安装托盘、四路超声波和黑色覆盖件

#### 8.1 处理托盘平整度

托盘打印完成后，先放到平面上检查四角是否翘起，中心连接区域是否平整。轻微翘曲可按材料特性处理；变形明显时应调整打印条件后重新打印。不要仅靠把四颗螺丝拧得很紧，把翘曲件硬拉到云台上，这会给连接处带来额外应力。

先用托盘主体与俯仰连接件试装，确认螺丝长度不会顶到舵机或活动件，再均匀锁紧。固定后托盘中心应与云台设计位置一致，避免偏心负载使倾倒晃动。

#### 8.2 在托盘四角安装超声波支架

超声波固定件的一面用于安装模块，背面与托盘角部贴合。先把模块放到平整的安装面，再将固定件背面粘接或按实际设计固定到托盘四角。

传感器要面向对应收集区域，不能朝向框架梁或挡板。托盘会旋转和俯仰，因此固定前先带着支架走一遍倾倒动作，检查探头、PCB 和接头是否碰撞下方桶壁。

线束沿托盘背面整理，再随云台留出弯曲余量。不能把传感器线拉得太紧，使托盘转动时直接拉扯模块针脚。

#### 8.3 按省赛工程接四路独立触发

四个 HC-SR04 分别使用独立的 Trig 和 Echo：

| 模块 | Trig | Echo |
| --- | --- | --- |
| 1 | PB14 | PC10 |
| 2 | PB12 | PC12 |
| 3 | PB5 | PC11 |
| 4 | PB7 | PB15 |

如果在合适的分配板上共用电源和地，对外仍需要 **2 根供电线 + 4 根 Trig + 4 根 Echo = 10 根线**。因此两个 4 pin 接口不足以承载这套独立布线。可重新选择接口数量，并标清各路编号。

程序依次测量四个模块，每路之间等待 100 ms，不是同时触发。第四路 Echo 的初始化有一处端口错误：头文件定义 PB15，但初始化函数把四路 Echo 都配置到 GPIOC。接好 PB15 后还需按软件章节中的说明修正初始化。

#### 8.4 安装黑色覆盖件

托盘固定完成后，覆盖黑色打印的 `托盘覆盖圆滑.SLDPRT`，遮住中间四颗螺丝。覆盖件边缘的圆滑过渡用于让垃圾倾倒时更容易滑落。

先检查覆盖件不会妨碍拆卸，不会在翻转时松脱，也不会把托盘边缘变成新的台阶。装好后把典型物体放到托盘不同位置，低速倾倒，观察是否在螺丝附近、边缘或覆盖件接缝处卡住。

最后开启补光检查画面。黑色背景和稳定照明是本项目的采集条件，更换颜色或表面材料后，需要重新验证识别和定位。

8. 安装托盘、超声波模块与黑色覆盖件（图1）

8. 安装托盘、超声波模块与黑色覆盖件（图2）

8. 安装托盘、超声波模块与黑色覆盖件（图3）

8. 安装托盘、超声波模块与黑色覆盖件（图4）

8. 安装托盘、超声波模块与黑色覆盖件（图5）

### 9. 安装四个收集桶、下部电源及走线管

#### 9.1 先检查收集桶的安装路径

底部十字型材把区域分成四格，中心安装云台，四个桶分别放入四格。桶体模型位于 `hardware/mechanical/` 中的对应文件，透明区域使用亚克力板配合制作。

不要只在 CAD 中确认“放进去以后不干涉”，还要确认桶体能从实际入口放进去。若云台、横梁或挡板装好后把桶的入口封住，应调整装配顺序，或把桶设计成可拆卸结构。

正式打印前，可以先打印局部角部或用板材模拟桶外形，确认尺寸及安装路径。桶体与框架之间留出装配间隙，不能依赖加热软化桶角后强行塞入。

#### 9.2 检查压缩机构相关结构

桶体和底部支撑曾为压缩推杆预留空间。基础版本不安装推杆时，可对避让区域作相应修改，保持桶体稳定支撑。取消某个部件后，要检查是否还有螺丝孔、开口或支架失去原来的用途。

四个桶装好后，逐一检查取出清理是否方便。不要把电源线永久压在桶底，也不要让满载垃圾取出时必须拔掉控制板上的细信号线。

#### 9.3 安装下部电源和方形走线管

下部 DC 模块为云台、挡板等负载分配电源。选择可以检查、调整和散热的位置固定，电路板与铝型材之间做绝缘处理，接线端子保留维护空间。

上下线路通过侧边黑色方管汇集。穿线前先按用途贴标签，确认线束长度能到达上部控制区。方管两端若有锐边，应处理后再穿线，避免反复移动或振动磨伤绝缘层。

云台和托盘属于活动部分，它们的线束应在进入固定方管前保留活动段；固定在桶壁上的线路则沿框架整理。把“固定线”和“随机构移动的线”分清，后面调挡板时会更容易发现干涉。

9. 安装四个收集桶与下部电源（图1）

### 10. 安装挡板、补光与外壳

#### 10.1 一面挡板的装配关系

正对一面挡板，一端用 `侧面柱子固定.SLDPRT` 固定支撑光杆，另一端用 `侧面舵机固定.SLDPRT` 固定舵机。两端分别连接 `挡板固定.SLDPRT` 和 `挡板固定舵机.SLDPRT`，再将挡板本体连接在中间。

先把支撑端和舵机端装到两根立柱上，但不要立即锁死高度。让两端转轴在同一高度，再试放挡板。若两端高低不一致，挡板转动时会扭曲或卡住，不应靠舵机强行带动。

#### 10.2 校准关闭位置

四个挡板舵机共用 PA2 的 PWM 信号。程序将 52°作为关闭参考，将 80°作为打开参考。因此四个舵机的舵盘安装方向必须一致，机械连接还要保证同一信号能让四面共同打开。

可先在脱离挡板负载时设到同一装配角度，再固定舵盘；随后分别试到 52°和 80°，确认动作方向。不是把四个舵机都装成外观相同方向就一定能正确动作，还要看每面的连杆连接方式。

挡板装上后，上下移动两端支架，让关闭时的下边缘与托盘边缘贴合，相邻两块挡板的侧边也能靠近。不要把四边挤得没有间隙，否则打印尺寸误差可能导致其中一块先顶住，其他舵机仍在继续用力。

#### 10.3 为走线管安排缺口

带缺口的挡板安装在黑色走线方管所在一侧。先检查缺口是否真正避开管子，再检查打开时是否会夹住穿出的线束。挡板的适配关系同时涉及托盘、支架和框架，改变整机尺寸后应整体核对。

四个舵机由下部电源供电，信号线并接到 PA2，地线与 STM32 信号参考地连接。并联信号不等于可以由 PA2 给四个舵机供电。

#### 10.4 安装补光和外壳

三块 WS2812 灯板安装在三根立柱上，机械爪回零所靠近的角落不装灯板，避免挤占滑台和夹爪空间。可使用 `LED固定.SLDPRT` 对应支架，先确认灯板与实际打印件匹配。

灯板由 Arduino 控制，具体接线按所用板卡和灯板规格确认。先固定亮度与颜色，再采集训练图像；运行时保持相同照明条件。当前省赛 STM32 工程没有 WS2812 控制入口，不要将工作指示灯 PA12 当作补光数据口。

外壳安装前，先完成全部空载动作。确认摄像头线、灯板线和电源线都固定好后，再安装遮光板、亚克力装饰和侧边压条。至少保留便于断电、拔插和取桶的维护路径。

外壳装好后重新看一次摄像头画面，再做四方向倾倒和四角抓取测试。盖板可能改变内部光线，也可能压住原先没有干涉的线束。

10. 安装四周挡板（图1）

10. 安装四周挡板（图2）

10. 安装四周挡板（图3）

10. 安装四周挡板（图4）

10. 安装四周挡板（图5）

10. 安装四周挡板（图6）

## STM32F103RCT6 接线与供电

### 1. 控制板型号与端口名称

下文按 **STM32F103RCT6** 控制板说明接线，省赛 Keil 工程的器件项为 `STM32F103RC`。`PA0` 表示 GPIOA 的第 0 位，`PB10` 表示 GPIOB 的第 10 位；这些是芯片端口名称，不是开发板排针从左往右的序号。

接线时按控制板丝印找到对应端口。不同厂家的开发板，端口在排针上的排列、5 V 输入和 3.3 V 输出位置可能不同，不能照另一块板的排针顺序连接。芯片封装与电气参数参考 [ST 官方 STM32F103xC/D/E 数据手册](https://www.st.com/resource/en/datasheet/stm32f103rc.pdf)。

下面的功能分配来自省赛工程实际加入编译的源文件。未在控制板实物上核对的电源输入位置、继电器端子及驱动器接插件，不用猜测的针脚代替。

### 2. 全部功能 IO 对照表

表中的输入、输出方向均以 STM32 为基准。

| STM32 IO | 方向与配置 | 连接对象 | 程序中的作用 | 对应文件 |
| --- | --- | --- | --- | --- |
| PA0 | 复用推挽输出，TIM2_CH1 | 云台水平旋转舵机信号 | 默认 90°，分类时转至 45°或 135° | `servo_drive.c`、`Low_Servo_App.c` |
| PA1 | 复用推挽输出，TIM2_CH2 | 云台俯仰舵机信号 | 默认 94°，倾倒时为 48°或 140° | 同上 |
| PA2 | 复用推挽输出，TIM2_CH3 | 四个挡板舵机的并联信号 | 默认关闭 52°，打开 80° | 同上 |
| PA4 | 推挽输出 | 压缩机构外部驱动的控制端 A | 默认高；与 PA5 组合控制方向 | `infrared.c` |
| PA5 | 推挽输出 | 压缩机构外部驱动的控制端 B | 默认高；基础版本不接压缩负载 | `infrared.c` |
| PA6 | 复用推挽输出，TIM3_CH1 | 机械爪旋转舵机信号 | 初始 85° | `servo_drive.c`、`Arm_Servo_App.c` |
| PA7 | 复用推挽输出，TIM3_CH2 | 夹爪开合舵机信号 | 张开 40°，夹紧 105° | 同上 |
| PA12 | 推挽输出 | 工作状态指示灯的兼容输入电路 | 初始化高，待机低，处理时高 | `workLED.c/.h` |
| PB0 | 复用推挽输出，TIM3_CH3 | 伸缩舵机 A 信号 | 抬升 70°，下降 20° | `servo_drive.c`、`Arm_Servo_App.c` |
| PB1 | 复用推挽输出，TIM3_CH4 | 伸缩舵机 B 信号 | 与 PB0 输出相同角度 | 同上 |
| PB5 | 推挽输出 | 超声波 3 Trig | 单独触发第三路测距 | `hc_sr04.h/.c` |
| PB6 | 推挽输出 | 第二台步进驱动器供电继电器的控制输入 | 初始化高，约 15 秒后拉低 | `infrared.c` |
| PB7 | 推挽输出 | 超声波 4 Trig | 单独触发第四路测距 | `hc_sr04.h/.c` |
| PB8 | 开漏输出，软件模拟 I²C | 调试 OLED 的 SCL | 调试显示时钟 | `OLED.c` |
| PB9 | 开漏输出，软件模拟 I²C | 调试 OLED 的 SDA | 调试显示数据 | `OLED.c` |
| PB10 | 复用推挽输出，USART3_TX | 树莓派所用 UART 的 RX | 发送拍照请求和满载状态 | `UART3_OpenMV.c` |
| PB11 | 上拉输入，USART3_RX | 树莓派所用 UART 的 TX | 接收分类、坐标和界面命令 | `UART3_OpenMV.c` |
| PB12 | 推挽输出 | 超声波 2 Trig | 单独触发第二路测距 | `hc_sr04.h/.c` |
| PB13 | 上拉输入 | 红外光幕的兼容信号输出 | 低电平触发投料检测 | `infrared.h/.c` |
| PB14 | 推挽输出 | 超声波 1 Trig | 单独触发第一路测距 | `hc_sr04.h/.c` |
| PB15 | 应配置为浮空输入 | 超声波 4 Echo | 第四路回波，需修正初始化端口 | `hc_sr04.h/.c` |
| PC0 | 推挽输出 | 左步进驱动器脉冲输入 | 软件产生左电机脉冲 | `stepper_motor.c` |
| PC1 | 推挽输出 | 右步进驱动器脉冲输入 | 软件产生右电机脉冲 | `stepper_motor.c` |
| PC2 | 推挽输出 | 左步进驱动器方向输入 | 左电机 DIR | `stepper_motor.c` |
| PC3 | 推挽输出 | 右步进驱动器方向输入 | 右电机 DIR | `stepper_motor.c` |
| PC10 | 浮空输入 | 超声波 1 Echo | 第一回波测量输入 | `hc_sr04.h/.c` |
| PC11 | 浮空输入 | 超声波 3 Echo | 第三回波测量输入 | `hc_sr04.h/.c` |
| PC12 | 浮空输入 | 超声波 2 Echo | 第二回波测量输入 | `hc_sr04.h/.c` |

共使用 **28 个功能 IO**，另需供电、GND 和下载调试接口。使用下载器时，SWD 接线按控制板的 SWDIO、SWCLK、GND 和参考电压标识连接；不要占用下载接口做其他模块连接。

### 3. 十个舵机如何接到七路 PWM

十个舵机并不需要十个独立通道，分配如下：

```text
TIM2_CH1 / PA0 ── 云台水平舵机
TIM2_CH2 / PA1 ── 云台俯仰舵机
TIM2_CH3 / PA2 ─┬─ 挡板舵机 1
               ├─ 挡板舵机 2
               ├─ 挡板舵机 3
               └─ 挡板舵机 4

TIM3_CH1 / PA6 ── 机械爪旋转舵机
TIM3_CH2 / PA7 ── 夹爪开合舵机
TIM3_CH3 / PB0 ── 伸缩舵机 A
TIM3_CH4 / PB1 ── 伸缩舵机 B
```

每个舵机的电源正极接到符合舵机规格的电源输出，负极接对应电源地，信号线接表中 IO。控制板与舵机信号需要共同的地参考，舵机大电流回路应通过电源分配线路，不应穿过控制板细排针承担全部电流。

PA2 只分配 PWM 信号给四个挡板舵机。四个舵机能否同步到位取决于舵盘角度和机构安装；同一个信号不能补偿四个机构不同的机械偏差。

两个伸缩舵机分别用 PB0、PB1，但应用层同时给它们写入相同角度。布线保留两路，有利于之后分别微调。

### 4. 两台步进电机与继电器

#### 4.1 脉冲、方向和电机供电是三件事

| 电机 | 脉冲信号 | 方向信号 | 软件方向电平 |
| --- | --- | --- | --- |
| Left | PC0 | PC2 | `dir=0` 输出高，`dir=1` 输出低 |
| Right | PC1 | PC3 | `dir=0` 输出高，`dir=1` 输出低 |

PC0～PC3 接的是驱动器控制输入，不接步进电机线圈。电机线圈连接驱动器电机端，驱动器另接符合规格的电源。

驱动器的脉冲、方向接口可能使用单端信号或带正负端子的接口形式。应根据实际驱动器手册完成电平和公共端连接，不能仅凭 `PUL`、`DIR` 名称猜测要接到哪个正负端。

#### 4.2 继电器控制

PB6 连接适配 STM32 输出电平的继电器控制模块，不能直接驱动继电器线圈。继电器触点用于控制后上电那台驱动器的供电路径，触点容量应与负载匹配。

接负载前先检查以下状态：

| 时刻 | PB6 | 要实现的实际状态 |
| --- | --- | --- |
| 初始化后 | 高 | 后上电驱动器保持断电 |
| 约 15 秒后 | 低 | 后上电驱动器获得供电 |

这张表描述期望的接线结果。模块若是高电平触发，或用了不同的常开/常闭触点，实际状态可能相反，需要调整模块或接法。

限位开关连接到先回零的驱动器，本程序未接收它们的独立反馈。两台电机中哪台作为延时上电电机，需要按实物布置确认，不能仅凭软件名称 Left/Right 推定。

### 5. 四路超声波接线与初始化修正

四路 Trig 都在 GPIOB，但 Echo 分散在 GPIOB 和 GPIOC。`HC_SR04_Init()` 中将全部 Echo 位掩码合并后，只调用了 `GPIO_Init(HC_SR04_ECHO1_PORT, ...)`，而 `HC_SR04_ECHO1_PORT` 是 GPIOC，结果会配置 PC15，却没有按测距需要初始化 PB15。

接线按 IO 表不变，在 `HC_SR04_Init()` 中将“配置所有 Echo”的代码块替换为下面的分端口初始化：

```c
/* Echo1=PC10，Echo2=PC12，Echo3=PC11 */
GPIO_InitStructure.GPIO_Mode = GPIO_Mode_IN_FLOATING;
GPIO_InitStructure.GPIO_Speed = GPIO_Speed_50MHz;
GPIO_InitStructure.GPIO_Pin = GPIO_Pin_10 | GPIO_Pin_11 | GPIO_Pin_12;
GPIO_Init(GPIOC, &GPIO_InitStructure);

/* Echo4=PB15 */
GPIO_InitStructure.GPIO_Pin = GPIO_Pin_15;
GPIO_Init(GPIOB, &GPIO_InitStructure);
```

这是供复刻时采用的修正片段，省赛压缩包中的源码未被此文档自动修改。

模块 VCC 按模块规格供电，Echo 接入前确认输出电平与 MCU 引脚的兼容条件；需要电平转换时在接口处完成。信号线和电源线标明模块编号，特别注意模块 2 用 PC12、模块 3 用 PC11，不能按编号顺序想当然地接成 PC11、PC12。

### 6. 串口、OLED、红外与工作灯

树莓派通信只需发送、接收和信号地：

```text
STM32 PB10 / TX ───── 树莓派对应 UART 的 RX
STM32 PB11 / RX ───── 树莓派对应 UART 的 TX
STM32 GND      ───── 树莓派 GND
```

树莓派程序打开 `/dev/ttyAMA0`。这个设备名不等于已经确定了物理接线位置，尤其在树莓派 5 上，应先确认 UART 的启用方式和引出接口，再接对应 TX/RX。这里不把未经核对的 40 pin 排针编号写为固定连接方案。

调试 OLED 与主触摸屏是两个设备：OLED 接 PB8/PB9，用于显示四路平均距离；主屏通过 HDMI/USB 接树莓派。OLED 程序模拟 I²C，发送的写地址字节是 `0x78`，对应七位地址 `0x3C`，选模块时需匹配控制器与显示参数。

红外光幕输出接 PB13，程序以上拉输入读取低电平触发。工作灯控制在 PA12，待机时输出低、忙碌时输出高；实物灯的亮灭还取决于灯或驱动模块有效电平。不要仅凭函数名判断灯一定是高亮低灭。

### 7. 压缩接口与没有启用的模块

PA4、PA5 是压缩机构的两个控制输出，`Condense()` 依次输出：高/低保持 10 秒，低/高保持 10 秒，最后高/高。外部驱动器如何把这三个状态解释为伸出、缩回和停止，需要根据实际驱动电路确认。基础版本不连接推杆，也不操作界面压缩按钮。

工程目录中的 `TIM3_PWM.c`、`UART1_VOFA.c`、`LED.c`、`Key.c` 和 `TIM6_Timer.c` 没有加入当前省赛工程的编译列表。不能因为目录里存在某个文件，就把其中引脚当作当前接线依据。特别是 `TIM3_PWM.c` 和 `servo_drive.c` 存在同名函数，前者还是不同的 PWM 配置，不要同时添加到工程。

### 8. 分组供电与第一次通电

采用电池输入、多个电源分支的方式：树莓派用专用供电模块，上部机械爪和控制区、下部云台与挡板分别进行电源分配，显示器按其额定输入供电。步进驱动器、舵机、灯板和控制板不一定使用同一个工作电压。

第一次通电按以下顺序进行：

1. 断电检查各接插件电源正负，确认没有把供电与信号插反。
2. 暂时断开负载，测量各电源模块的输出，再连接对应设备。
3. 单独给控制板和屏幕、树莓派上电，先验证显示、通信与启动。
4. 舵机不带负载时逐个验证 PWM，再安装机械连接件。
5. 测试 PB6 及继电器的 15 秒状态变化，然后接入步进驱动器。
6. 低速验证回零与运动，最后才进入完整分拣。
7. 多舵机同时动作时观察是否掉电重启、画面中断或电源异常，确认后再装外壳。

## 省赛 STM32 程序详解

### 1. 打开正确的工程

打开 `firmware/stm32/Project.uvprojx`。本目录由省赛 `垃圾分类STM32_机械臂(3.19).rar` 展开，原压缩包位于本地 `.local-archive/original/代码/省赛代码/`。工程保存的编译器信息为 **ARMCC V5.06 update 5（build 528）**，目标器件为 `STM32F103RC`，启动文件为 `startup_stm32f10x_hd.s`。

`Hardware/` 放外设驱动与动作函数，`System/` 放延时和 TIM7 配置，`User/main.c` 是完整分拣入口。先保留工程原有文件列表，再进行参数修改，避免把目录里的测试文件全部加入编译。

`.local-archive/original/代码/垃圾分类STM32/` 是另一份工程，其中的 `main.c` 是单路超声波测试入口。它适合参考模块测试方法，但不用于替代本节的省赛主程序。

### 2. 时钟、定时器和 PWM 是怎样分工的

启动代码启用了 72 MHz 配置，非互联型分支使用 HSE × 9，头文件默认 HSE 为 8 MHz。Keil 工程元数据里还出现 12 MHz 的时钟字段，不能据此判断开发板实物晶振。烧录前应检查实际晶振、`HSE_VALUE` 和启动时钟配置相互匹配。

以下定时结果按程序预期的 72 MHz 定时器时钟计算：

| 资源 | 用途 | 配置与计算 |
| --- | --- | --- |
| TIM2 | 托盘水平、托盘俯仰、挡板 PWM | 分频 `72-1`，周期 `20000-1`，计数步长 1 μs、周期 20 ms |
| TIM3 | 机械爪四路 PWM | 同样为 20 ms 周期 |
| TIM4 | 步进脉冲的时间间隔参考 | 根据 `speed` 设置分频，轮询更新标志后翻转 PC0/PC1 |
| TIM6 | 超声波触发延时和 Echo 计时 | 分频 `72-1`，16 位计数 |
| TIM7 | 上电延时与红外检测重新使能 | 分频 `7200-1`，周期 `10000-1`，约每秒中断一次 |
| USART3 | 树莓派通信 | 115200，8 位数据，无校验，1 位停止位 |

舵机函数把目标角度转换为比较值：

```c
compare = degree / 180.0f * 2000 + 500;
```

在上述时钟下，0°、90°、180°分别对应约 500 μs、1500 μs、2500 μs 的高电平。这里说明的是程序输出关系，实际舵机能否覆盖这个范围，应按舵机规格和机械限位验证。函数没有自动限制输入角度，所以调用方不能随意传入越界值。

### 3. 从上电到等待投料

`main.c` 的初始化顺序为：

```c
workLED_Init();
OLED_Init();
UART3_OpenMV_Init(115200, 0, 1);
Catch_Init();
Low_Servo_Init();
IR_Init();
HC_SR04_Init();
Low_Servo_Reset();
```

逐项作用如下：

1. `workLED_Init()` 将 PA12 设置为输出并置高，设备先处于初始化状态。
2. `OLED_Init()` 初始化调试屏。
3. `UART3_OpenMV_Init()` 准备 PB10/PB11 通信和接收中断。
4. `Catch_Init()` 初始化步进控制 IO、机械爪 PWM，并启动 TIM7 的 1 秒节拍。
5. `Low_Servo_Init()` 初始化云台与挡板 PWM，并设置复位角度。
6. `IR_Init()` 设置光幕 PB13、继电器 PB6 和压缩控制 PA4/PA5。
7. `HC_SR04_Init()` 初始化四路测距 IO 及 TIM6。
8. 再次调用 `Low_Servo_Reset()`，确认托盘和挡板处于接收垃圾的姿态。

之后主程序先延时 1 秒，再等待串口接收标志。接收状态机刚启动时只接受字符 `'6'`，因此实际需要在树莓派界面进入识别页面，通过 `unlock()` 发送 `'6'`。

收到启动字符后，主程序还会等待 `Start_Flag`。TIM7 累计到约 15 秒时，将 PB6 拉低并把 `Start_Flag` 设为 1。也就是说，**界面已经打开，不代表设备立即可以投料；串口解锁和上电等待两个条件都要满足。** 这 15 秒从 TIM7 启动计时，不是从按下界面按钮开始。

### 4. 红外触发和三个流程标志

主循环使用以下标志区分是否要等一批新垃圾：

| 标志 | 作用 |
| --- | --- |
| `IR_Detected` | 本次读取光幕发现低电平遮挡 |
| `break_flag` | 混合垃圾抓走一个后，需要再次走 `Start` 识别流程 |
| `check_flag` | 已进行一次倾倒，随后进入 `Check` 清理复检流程 |

在普通待机状态，`break_flag`、`check_flag` 都为 0，主程序将 PA12 拉低，并持续调用 `IR_Detection_Process()`。

光幕触发后，函数将 `IR_Detected` 设为 1，暂时关闭重复检测，并等待 50 ms。TIM7 每秒清除 `IR_Detected`，对关闭检测的时间进行累计，经过三个计时节拍后重新允许检测。

这并不是一套“整轮分拣结束后才重新使能”的严格忙碌锁。是否等待新投料还由主循环及 `break_flag`、`check_flag` 决定。因此操作时应遵守工作指示状态，不在忙碌期间连续投料。

普通新投料触发后，STM32 等待 **2 秒**，让垃圾落到托盘并稳定，然后发送 `Start\n`。如果正在处理前一轮的后续动作，就跳过这段新投料等待。

### 5. 一次识别结果回来后，主程序做什么

发送 `Start\n` 或 `Check\n` 后，主程序等待 `UART3_GetRxFlag()`，取得 `UART3_GetRxData()`。返回数据按以下方式处理：

| 接收结果 | 主程序执行 |
| --- | --- |
| `'6'` | 返回循环，不执行分类动作 |
| `'1'`～`'4'` | 打开挡板，调用对应类别的托盘倾倒 |
| 完整抓取帧，最后一个字符为 `\n` | 读取 `RxInfo`，调用 `Catch(info.x, info.y, 85, info.type)` |
| `'9'` | 执行平均距离检测，清除 `check_flag`，复位托盘与挡板 |

对于倾倒指令，程序实际通过 `react_data & 0x0F` 将 ASCII 数字的低四位转成类别编号。对于抓取帧，接收函数完成整帧后，最后的 `RxData` 是换行，因此主程序以 `react_data == '\n'` 判断进入抓取分支。

当前实现没有先对所有字符做完整的合法性验证。例如收到其他字符时，也可能落入按低四位取值的分支。因此串口调试要使用协议规定的字符，不随意发送带回车换行的杂项文本。

### 6. 单个目标和同类目标：托盘倾倒

单个目标、或同一张图中所有目标属于同一大类时，上位机只发送类别字符，不发送坐标。STM32 把挡板设为 80°后，调用 `Low_Servo_React()`。

| 类别指令 | 垃圾类别 | 水平舵机 PA0 | 俯仰舵机 PA1 |
| --- | --- | --- | --- |
| `'1'` | 有害垃圾 | 45° | 140° |
| `'2'` | 厨余垃圾 | 135° | 140° |
| `'3'` | 可回收物 | 45° | 48° |
| `'4'` | 其他垃圾 | 135° | 48° |
| 复位 | 接料位置 | 90° | 94° |

水平转动使用每次变化 1°、等待 20 ms 的方式靠近目标；俯仰调用直接写目标角度。主程序执行倾倒后等待 1 秒，再设置 `break_flag=0`、`check_flag=1`。

随后调用 `Low_Servo_Reset()`，先让水平与俯仰回到 90°、94°，等待 200 ms，再将挡板设为 52°。下一轮不等待新的红外触发，而是向树莓派发 `Check\n`，检查有没有残留垃圾。

`Low_Servo_RotateHorizontal()` 的循环起点按 90°附近编写，依赖调用前机构已复位，并不是从任意实际角度平滑转到目标的通用函数。调试时如果跳过复位直接调用，运动行为可能与预期不同。

### 7. 混合目标：机械爪抓取

`Catch()` 接收四个参数：图像 X、图像 Y、夹爪旋转目标和垃圾类别。主程序固定把旋转目标传为 85°。

抓取过程按源码顺序如下：

| 步骤 | 函数或动作 | 参数/等待 | 目的 |
| --- | --- | --- | --- |
| 1 | `Core_XY(point_x, point_y, 1000, 1)` | 图像坐标模式 | 移到目标上方 |
| 2 | `Low_Servo_SetGuard(80)` | 挡板打开 | 为后续转移让位 |
| 3 | `Arm_Servo_SetCompareRevolve(angle)` | 主程序传 85° | 调整夹爪朝向 |
| 4 | `Arm_Servo_SetCompareDown(20)` | 等待 500 ms | 两个伸缩舵机共同下降 |
| 5 | `Arm_Servo_SetCompareGrab(105)` | 等待 1000 ms | 夹取物体 |
| 6 | `Arm_Servo_SetCompareDown(70)` | 无单独等待语句 | 抬起物体，随后还会进行托盘转动 |
| 7 | `Low_Servo_RotateHorizontal(45)` | 逐步转动 | 调整下部通道 |
| 8 | 按类别执行机械坐标移动 | 见下表 | 将物体运到对应桶上方 |
| 9 | 等待后开爪 | 先等 100 ms，开至 40°，再等 500 ms | 释放物体 |
| 10 | `Low_Servo_RotateReset()` | 按 46°到 90°写角度 | 恢复托盘水平旋转参考 |
| 11 | 经过中间点，旋转设回 85° | 按类别选择路径 | 返回并避让 |
| 12 | 挡板 52°，`Core_XY(0,0,1000,0)` | 机械坐标模式 | 回初始位置 |

类别投放路径不是根据摄像头即时计算，而是保存在代码中的固定坐标：

| 类别 | 去程 | 投放时旋转舵机角度 | 返回中间点 |
| --- | --- | --- | --- |
| 1 有害 | 到 `(210,10)` | 170° | `(100,100)` |
| 2 厨余 | 经 `(160,190)` 到 `(210,240)` | 85° | `(100,100)` |
| 3 可回收 | 到 `(0,240)` | 85° | `(50,190)` |
| 4 其他 | 经 `(50,50)` 到 `(0,0)` | 85° | 无额外中间点 |

这些坐标属于本机机械坐标体系，实际单位与脉冲换算需要按机构标定。换桶位、改变框架或改变夹爪尺寸后，应重新验证路线，不能直接让机构高速跑到这些坐标。

若抓取发生在 `check_flag=0` 阶段，主程序把 `break_flag` 设为 1，使下一轮再发送 `Start`。这样混合目标抓走一个后，会重新判断剩下的垃圾是否已经全部同类；如果已经同类，就可以整体倾倒。

若已经进入 `Check` 阶段，上位机对剩余目标继续发送抓取帧，直到无目标时返回 `'9'`。因此 `Start` 和 `Check` 的策略不同，不只是函数名字不同。

### 8. CoreXY 坐标换算与步进脉冲

#### 8.1 两种坐标输入

`Core_XY(input_X, input_Y, speed, type)` 的 `type=0` 表示直接输入机械坐标，`type=1` 表示先把图像坐标转换为机械坐标。

省赛代码中的仿射系数为：

```text
x = -0.442060 × u - 0.001511 × v + 204.414347
y = -0.002453 × u + 0.447338 × v + 18.974381
```

接着在 `Core_XY()` 中又加了安装偏移：

```text
X_target = point.x + 44
Y_target = point.y - 22
```

这里 `point.x`、`point.y` 的类型是 `uint16_t`，所以程序先把仿射结果转成整数，再加偏移。标定时既要核对仿射系数，也要核对这两个偏移；上位机不能先转一次，再把结果按图像模式送进来。

还要在转换后检查范围。负数结果、`point.y < 22` 或超出机械行程的坐标，不应直接进入无符号坐标变量后驱动电机。

#### 8.2 从平面位移到电机脉冲

程序保存当前位置 `X_current`、`Y_current`，计算与目标的差值：

```text
dx = X_target − X_current
dy = Y_target − Y_current

stp_1 = (dx − dy) × 160
stp_2 = (dx + dy) × 160
```

脉冲正负用于决定方向，脉冲数量用于决定移动距离。两台电机共同形成 XY 位移，因此交换电机、改变皮带绕向或反转电机方向后，都需要重新核对这套符号关系。

系数 160 是当前程序的标定常数。注释记录为 32 细分、每圈 6400 脉冲，但最终是否对应每毫米 160 脉冲，还要同时确认轮的齿数、齿距和驱动器设置。先用小范围移动测量实际位移，再确定换算关系。

`X_current`、`Y_current` 上电初始化为 0，完成发脉冲后直接更新为目标值；STM32 没有读取实际位置确认。因此即使驱动器没有报警，外力滑动、皮带打滑或错误回零都会让软件坐标与实际位置不一致。

#### 8.3 `speed` 参数的含义

代码通过 `(SystemCoreClock / 1000000) * (1000 / speed) - 1` 设置 TIM4 分频，再使用 `period=49`。这里有整数除法，`speed` 并不与实际速度连续线性对应，也不是 mm/s。

不能传入 0，否则发生除零；也不要超出代码预期范围。单电机、72 MHz 时钟且 `speed=1000` 时，定时器更新间隔按配置约为 50 μs，但实际脉冲还受软件轮询影响。

双电机函数中的两个分支读取并清除同一个更新标志，不能把它当作严格同步的硬件双轴插补。高速运行前应先低速观察轨迹，再用示波器或逻辑分析仪验证脉冲。

`Core_XY()` 中还需要检查一个方向分支：当 `stp_1<0` 且 `stp_2==0` 时，代码将左脉冲取正，却令 `dir_1=1`，与其他左负向分支使用的 `dir_1=0` 不一致。复刻时应先修正并验证这个方向分支，再测试相关对角线运动。目标与当前位置完全相同时，也应直接返回，避免将未赋值的方向变量传入底层函数。

### 9. 满载检测不是简单地读四个数

#### 9.1 单路测距

`MeasureDistance()` 对指定 Trig 输出 10 μs 高电平，再等待 Echo 变高，用 TIM6 记录高电平宽度，最后按以下公式计算厘米值：

```text
distance_cm = echo_time_us × 0.0343 / 2
```

四路顺序测量，每路之后延时 100 ms，以减少前一次发射对后续测量的影响。代码中的 `timeout=50000` 是循环次数递减，不是准确的 50000 μs 超时计时。

#### 9.2 转动托盘进行多位置测量

`HC_SR04_Get_Average_Distances()` 先将水平、俯仰复位，等待 500 ms，然后依次在水平 70°、90°、110°附近采集四路测距结果，最后将水平设回 90°。

注意实际语句顺序是写入一个新角度后立即开始测距，500 ms 延时位于这一组测量之后。这意味着不能声称每次测量前都已经等待舵机稳定。复刻时应检查实际运动时间，必要时把稳定等待明确放在写入角度之后、开始测量之前。

#### 9.3 平均方式、阈值与状态编号

| 传感器 | 使用的采样姿态 | 满载阈值 | 满载消息 | 未满消息 |
| --- | --- | --- | --- | --- |
| 1 | 70°、90°、110°三次平均 | 小于 16 cm | `Four\n` | `Fempty\n` |
| 2 | 70°、90°、110°三次平均 | 小于 16 cm | `Two\n` | `Tempty\n` |
| 3 | 70°、90°、110°三次平均 | 小于 16 cm | `Three\n` | `Rempty\n` |
| 4 | 70°、90°两次平均 | 小于 13.8 cm | `One\n` | `Oempty\n` |

第四路虽然也采集第三次数据，但平均公式只使用前两次。以上明确写出当前行为，不能把它笼统理解为“四路各取三次平均”。

消息编号与传感器编号不是 1 对 1 顺排，安装完成后要依次把物体放到每个探头下方，观察 OLED 和 Qt 界面变化，再确定桶位标签。不要仅根据 `One` 这个名称把探头接成第一路。

超时返回 `-1`，当前平均函数没有剔除该值，可能把无效测量当成很近的物体而误报满载。应先区分有效距离和错误状态，再计算平均值；不能为了消除误报只把满载阈值改小。

### 10. 串口协议和接收状态机

#### 10.1 报文内容

| 方向 | 数据 | 含义 |
| --- | --- | --- |
| STM32 → 树莓派 | `Start\n` | 新一轮或混合抓取后的再次识别 |
| STM32 → 树莓派 | `Check\n` | 倾倒后的残留复检 |
| STM32 → 树莓派 | `One/Two/Three/Four` 加换行 | 对应状态满载 |
| STM32 → 树莓派 | `Oempty/Tempty/Rempty/Fempty` 加换行 | 对应状态未满 |
| 树莓派 → STM32 | `'1'`、`'2'`、`'3'`、`'4'` | 四类垃圾的整体倾倒 |
| 树莓派 → STM32 | `'5' + XXX + YYY + C + '\n'` | 按图像坐标抓取 |
| 树莓派 → STM32 | `'6'` | 解锁接收流程 |
| 树莓派 → STM32 | `'7'` | 压缩操作 |
| 树莓派 → STM32 | `'8'` | 主动满载检测 |
| 树莓派 → STM32 | `'9'` | `Check` 没有检测到目标 |

单字符命令按 ASCII 发送，不附加换行；坐标帧最后必须有一个换行。实际抓取帧共 **9 字节**：1 字节 `'5'`、3 字节 X、3 字节 Y、1 字节类别、1 字节换行。

例如 X=123、Y=85、类别=3：

```python
packet = b"51230853\n"
# 拆分：b"5" + b"123" + b"085" + b"3" + b"\n"
```

Python 使用 `:03d` 格式化坐标，它只保证至少三位，超过 999 不会自动截断。发送前应校验坐标和类别，接收端也应拒绝非数字、越界坐标和错误长度。

#### 10.2 状态机怎样读取抓取帧

| 状态 | 等待或执行内容 | 下一状态 |
| --- | --- | --- |
| 0 | 等 `'6'`，收到后置接收标志 | 1 |
| 1 | 等普通指令；收到 `'5'` 进入坐标接收 | 2 |
| 2 | 收满 7 个有效载荷字符，存入缓冲区 | 3 |
| 3 | 等待 `\n`，完整帧置接收标志、清计数 | 1 |

`UART3_GetRxInfo()` 从前三位取 X、中间三位取 Y、最后一位取类别。转换方式是数字字符低四位乘百位、十位和个位，没有额外检查字符确实是 `'0'` 到 `'9'`。

状态 3 收到错误结束符时没有完整的超时恢复逻辑，丢字节或发送格式不符会导致后续接收错位。独立测试时，先重启控制板，再发送 `'6'`，再用已知报文检查解析结果，之后才接入运动流程。

#### 10.3 中断里执行长动作的问题

接收到 `'7'` 时，中断直接调用 `Condense()`，其中包含两段 10 秒等待；接收到 `'8'` 时，中断直接执行挡板操作、测距和复位。这样的长动作会占用串口中断，并影响同级中断和后续消息处理。

改进时应让接收中断只保存命令和置位标志，把压缩或满载检测放到主循环中执行。本文说明当前控制逻辑和复刻注意点，不把它当作已经具备完整异常恢复能力的通用控制框架。

## 树莓派视觉、Qt 界面与模型训练

### 1. Python 工程结构及启动入口

使用 `software/raspberry-pi/main.py`。本目录由省赛 Python 压缩包展开：

```text
software/raspberry-pi/
├── main.py                 # 应用入口、串口线程、识别和界面桥接
├── qml/
│   ├── main.qml            # 主窗口与页面加载器
│   ├── Mainpage.qml        # 首页，进入识别页时发送解锁指令
│   ├── Cvpage.qml          # 识别结果、计数、满载状态与操作按钮
│   ├── Checkpage.qml       # 另一个界面页面
│   ├── Videopage.qml       # 视频展示页
│   ├── UI_2.1/             # 界面图片资源
│   └── 1.mp4               # 展示视频
├── yolo/
│   ├── best.pt             # 部署权重
│   └── pics/               # 带检测框的结果图片
└── Makefile
```

不要把 `qml/` 里的另一个 `main.py` 当作默认启动入口。根目录应用依赖 `yolo/best.pt`、`qml/main.qml` 等相对路径，启动时的工作目录必须正确。

依赖包括 `ultralytics`、OpenCV、pyserial 和 PySide6。操作系统、Python 和库版本需要在实际树莓派环境中验证后锁定；不能只依据源文件 imports 保证任意最新版本都可以直接运行。

### 2. 程序启动后做了什么

主入口依次建立 `QGuiApplication`、`QQmlApplicationEngine` 和 `VideoFrameProvider`，将图像提供器注册为 `videoFrameProvider`。

`TestSystem` 对象初始化时：

1. 通过 `YOLO("yolo/best.pt")` 加载模型。
2. 以 115200 打开 `/dev/ttyAMA0`。
3. 初始化识别次数、显示序号和四个满载状态变量。
4. 启动运行 `serial_receive()` 的 QThread。

随后把 `TestSystem` 以 `videoCapture` 名称暴露给 QML，加载 `qml/main.qml` 并进入 Qt 事件循环。

所以模型文件错误、串口不存在或没有权限，都可能使程序在显示正常界面前就失败。排查时应分别验证这三件事，不要先怀疑摄像头或 STM32。

### 3. `serial_receive()`：树莓派等待谁来触发

树莓派不是一直对摄像头每一帧做分类，而是等待 STM32 发来的消息：

- 收到 `Start`：打开编号 0 的摄像头，读取一帧，调用 `test_send()`，再释放摄像头。
- 收到 `Check`：同样拍摄一帧，调用 `check()`，再释放摄像头。
- 收到满载/未满消息：修改 `one`、`two`、`three`、`four`，向 QML 发 `is_full` 信号。

串口读取使用 `readline().decode('utf-8').strip()`，因此 STM32 发来的文本应以换行结束。当前接收端没有完善的读取超时和异常恢复；遇到缺失换行或设备断开时，需要检查实际阻塞和错误行为。

摄像头每次重新打开后只取一帧。如果发现亮度不稳定或首次画面发暗，应检查曝光稳定时间，再决定是否预热后取帧；这属于需要验证的改进，并非当前代码已经做了多帧筛选。

### 4. `test_send()`：第一轮识别如何决定倒还是抓

调用 `self.model.predict(frame, conf=0.7, verbose=False)` 后，程序绘制检测框，将结果保存到 `yolo/pics/test_序号.jpg`，同时更新界面图像。

对每个检测框，程序读取模型类别名，再通过 `trash_dict()` 映射为四类垃圾：

| 四类垃圾 | 模型类别名 |
| --- | --- |
| `harmful` 有害 | `battery`、`drug` |
| `kitchen` 厨余 | `potato`、`carrot`、`daikon` |
| `recycle` 可回收 | `plastic`、`metal`、`cup` |
| `others` 其他 | `brick`、`cobblestone`、`porcelain` |

随后按检测结果决定：

| 结果 | 发送行为 |
| --- | --- |
| 只有一个目标 | 发对应类别字符，整体倾倒 |
| 多个目标，但映射后都是同一大类 | 发一个类别字符，整体倾倒 |
| 多个目标，包含不同大类 | 选择一个目标，发坐标抓取帧 |

同类判断比较的是四大类。例如两个不同的模型名称只要都映射为 `recycle`，就可以走同类倾倒。

抓取目标的选择不是距离最短或置信度最高：`test_send()` 把有害垃圾放到列表尾部，其他类别插到列表头部，再取第一个。所以其效果是在这个列表策略下优先取非有害目标，而不是经过抓取难度计算的最佳目标。

坐标来自 `box.xywh` 的前两项，即检测框中心 X、Y。程序没有用分割掩码或夹爪接触点估计，也没有对相邻物体进行抓取空间检查。两个物体靠近时被同时抓起，正与这一策略的局限相关。

**首次识别没有检测框时，当前函数会随机取一个模型类别，显示并发送倾倒指令。** 这不是识别成功。正式复刻建议改成有限次数重拍和未识别提示，不把这个分支计入准确率或正确分类数量。

### 5. `check()`：倾倒后怎样清理残留

`check()` 使用相同的模型阈值及图像保存流程，但决策不同：有目标就选一个并发送坐标抓取帧；没有目标就发 `'9'`。它不会因为剩余目标全部同类而再次发送整体倾倒指令，也没有首次识别函数中的随机分类分支。

`check()` 选择目标时使用列表插入顺序，不保留 `test_send()` 中有害类别后置的规则。不能把两个函数理解为完全相同的检测函数。

主程序收到 `'9'` 后进行满载检测、托盘复位并回到等待投料。这个闭环是“拍照—执行—重新拍照”，但没有夹爪上的抓取成功传感器；识别到的目标是否真正落入正确桶，需要通过整机测试确认。

### 6. Qt 图像、数量和按钮如何连接

图像显示流程为：OpenCV 结果图 → BGR 转 RGB → `QImage` → `VideoFrameProvider.update_image()` → `frame_ready` 信号 → QML 刷新 `image://videoFrameProvider/frame`。

数量显示使用 `find_trash` 信号。单目标或同类批量时，程序在发出动作指令之前就发出计数信号，并不是收到机械动作完成确认后计数。`check()` 中也没有相同的逐个计数逻辑。因此界面统计反映的是当前代码中的识别/指令记录，不能直接作为成功入桶数量。

主要按钮与命令的关系如下：

| 界面操作 | Python 方法 | 串口内容 |
| --- | --- | --- |
| 首页进入识别页面 | `unlock()` | `'6'` |
| 压缩按钮 | `condense()` | `'7'` |
| 满载检测按钮 | `checkFull()` | `'8'` |
| 首页退出按钮 | QML `Qt.quit()` | 不发送串口命令 |

退出按钮当前退出 Qt 应用，不等于关闭树莓派操作系统。基础版本未连接压缩机构时，不使用压缩按钮。

`main.qml` 的自动切换计时器 `interval` 为 50000，即约 50 秒。显示页面与图像资源仍需保持目录关系，屏幕分辨率变化时应同时调整布局。

满载状态的显示顺序需要与传感器表一起校准。不要把界面第一行、协议 `One`、传感器 1 和类别编号 1 当成天然一致的四个概念。

### 7. 数据准备与模型训练

#### 7.1 在最终装置上采集

先固定镜头、托盘高度、黑色覆盖件和补光，再采集图像。数据需要包含：单个垃圾不同朝向、托盘中心和四角、多个同类目标、混合目标、相邻和遮挡场景，以及空托盘。

先做一批小样本训练与部署，检查识别类别、坐标和实际抓取是否一致，再扩大数据量。否则可能花很多时间标注了与最终摄像头和照明条件不一致的数据。

#### 7.2 标签与类别保持配套

`tools/dataset/legacy/tool_1.py` 按 80%/20% 随机划分训练和验证图片，并复制同名标签。使用前需修改路径、检查标签是否齐全，并记录划分方式。连续拍摄的近似画面宜按批次分组，避免验证集与训练集过于相似。

`tool_2.py` 会直接改写标签编号，将若干细分类合并成四类。它不能不加检查地用于省赛权重：省赛 Python 按具体物体名称查 `trash_dict()`，如果模型已经变成只有四个大类名称，需同步修改应用映射。

运行任何标签重写脚本前，先保留未修改数据。训练数据配置中的 `names`、标签编号、部署权重的 `model.names` 与 Python 映射应作为一套版本保存。

#### 7.3 训练和推理脚本

训练入口位于 `tools/vision/train.py`，从仓库根目录显式指定初始权重与数据配置：

```sh
python3 tools/vision/train.py --weights models/local/initial.pt --data datasets/local/data.yaml --epochs 500
```

命令中的文件需要先准备好。程序先检查路径，再加载权重并训练，输出默认放入 `outputs/training/`。500 是请求训练的轮数，不是已经完成训练的证据，也不是自动续训配置。

图像测试入口为 `tools/vision/test.py`：

```sh
python3 tools/vision/test.py --source datasets/local/test_images
```

默认加载本地 `software/raspberry-pi/yolo/best.pt`，结果按 `result_0.jpg` 等保存到 `outputs/test_result/`。可以通过 `--weights` 和 `--output` 指定其他位置。图像测试不连接摄像头或 STM32。

历史脚本和训练资料仍保存在本地 `.local-archive/original/代码/树莓派/`，标签处理脚本在 `tools/dataset/legacy/`。验证通过后，再将确定的权重放入应用的 `yolo/best.pt`，记录模型来源、类别定义和验证结果。

没有完成实测前，不填写推测的准确率、FPS 或分拣成功率。

### 8. 重新标定图像坐标

`tools/calibration/main.py` 使用 19 组点，通过最小二乘拟合二维仿射关系。实际矩阵构造使用 `dst` 作为输入、`src` 作为输出，变量名称不应替代对真实数据含义的确认。

标定步骤：

1. 完成机械回零，确认机械坐标原点和正方向。
2. 在托盘上选择覆盖整个区域的标记点，记录其图像中心坐标。
3. 小范围移动夹爪，记录夹爪实际对准每个标记时的机械坐标。
4. 整理成一一对应的数据，明确输入是像素、输出是机械坐标。
5. 拟合转换系数，并检查固件中额外 `+44/-22` 偏移是否仍需要。
6. 使用没有参与拟合的点测试误差，记录四角、边缘和中心的偏差。
7. 将确认后的系数写入 `transform_coordinates()`，加入可达范围检查。

只在拟合用的 19 个点上打印误差，不能代表新位置也准确。摄像头调整后必须重做标定，机械回零重复性不好时也不应先靠改系数掩盖误差。

### 9. 手动部署、运行与自启动

树莓派使用 Ubuntu 24.04.1 LTS 桌面版的配置过程，以及 SSH、Python 3.10.16、PyTorch 和 YOLOv8 安装命令，见 [树莓派 YOLOv8 环境配置](raspberry-pi-yolov8-setup.md)。[完整 TXT 命令记录](搭建yolov8环境.txt) 同时保留，配置仍需在目标设备上重新验证。

先在树莓派上建立实际可用的环境，再记录系统版本、Python 版本及各依赖版本。确认以下项目后，从仓库根目录执行 `sh software/raspberry-pi/run.sh`，启动器会进入应用目录并运行 `main.py`：

1. 权重可加载，类别名称与映射匹配。
2. 摄像头编号正确，能稳定读取图像。
3. 串口实际存在、已启用、权限正确，TX/RX 接线已验证。
4. `qml/` 图片和视频资源完整，屏幕触控可用。
5. `yolo/pics/` 存在并有写入权限。
6. STM32 已完成单模块调试，运动区域没有障碍。

进入识别页面后，应用发送 `'6'`。等约 15 秒回零等待条件满足，确认设备进入待机，再放入第一个测试物体。

手动启动稳定后再配置开机自启动。启动配置必须指定实际 Python 解释器、工作目录、图形会话和日志位置。自启动还应能处理串口或摄像头暂未就绪的情况。当前资料没有核实可直接沿用的最终自启动文件，需在实际系统上配置并通过冷启动测试。

应用会不断保存结果图片。`Makefile` 中的 `clean` 会删除 `yolo/pics/` 下的 JPG，清理前先保留需要分析的测试图片。

## 分阶段调试与整机制作验收

### 1. 先制作一个不会自动运行全套动作的调试版本

正式主程序会在初始化时设置多个舵机位置，并启动回零等待计时。装配过程中应使用单模块调试入口，逐个验证外设，再恢复完整 `main.c`。保存调试版本和正式版本，避免临时改动后忘记恢复。

先不装机械负载，验证各路 PWM 与标记对应；再安装舵盘、连杆和托盘。运动测试从小角度、小位移开始，不直接执行完整抓取函数。

### 2. 舵机逐路标定

| 次序 | 操作 | 观察结果 |
| --- | --- | --- |
| 1 | PA6 旋转舵机设到装配参考位 | 只有旋转舵机动作 |
| 2 | PA7 从张开参考向夹紧方向小幅变化 | 夹爪开合方向正确，无连杆卡死 |
| 3 | PB0、PB1 分别检查，再共同输出 | 两侧伸缩方向配合，机构不扭曲 |
| 4 | PA0、PA1 分别验证水平和俯仰 | 托盘不会与桶、框架或线束碰撞 |
| 5 | PA2 先接一面挡板，再接四面 | 四面开合方向一致，关闭时不会互相顶住 |

标定表应记录实际采用的初始角、工作角、可用范围和舵盘安装方向。修改舵盘位置后，应重新检查相关全部动作，而不是只测试复位一次。

### 3. 回零和机械坐标验证

先验证继电器上电时序，再验证两个限位开关在预期位置动作。回零完成后，在空载情况下做短距离正 X、负 X、正 Y、负 Y 移动，观察方向和位移。

然后测试只需一台电机运动的两条对角线，以及连续多次往返。确认没有卡滞和丢失位置后，才验证 `(210,240)` 等投放位置。不能在坐标原点尚未确认时直接运行抓取程序。

断电重新启动，多次记录滑台实际回零位置。如果偏差已经大于夹爪可接受的范围，应先调整回零机构和限位，之后再做视觉标定。

### 4. 串口独立测试

先让 STM32 只记录收到的类别和坐标，不带动机构。核对 115200、8N1，发送 `'6'` 解锁，再验证单字符命令和抓取帧。

测试抓取帧时分别使用 X/Y 的一位、两位和三位数值，确认 Python 补零与 STM32 解析一致。再模拟错误字符、缺少换行和超范围坐标，检查程序会不会停在错误状态；补全恢复处理后再进入整机联动。

串口监视工具不能与主应用同时占用同一个设备。完成监视测试后关闭工具，再启动应用。

### 5. 超声波和桶位检查

先按说明修正 PB15 初始化，单独连接一路测试距离，再加入其余三路。将平整物体放在探头前不同距离，确认读数变化合理，并观察没有回波时返回的错误值。

四路都正常后，再执行托盘 70°、90°、110°多姿态测量。记录桶为空、接近满和已满时的读数，按实际探头位置重新确认阈值。

逐桶模拟满载并观察界面，检查四件事是否一致：探头编号、物理桶位置、发送消息和界面显示位置。若出现“遮住一个桶，另一个桶显示满”，优先排查映射，不立即调阈值。

### 6. 单目标和同类多目标

先从每类一个目标开始，分别验证四个倾倒方向。物体放在托盘中心、边缘和四角时都要测试，观察是否卡在覆盖件接缝、挡板或桶沿。

再放入多个同类目标，检查一次倾倒后是否有残留，`Check` 是否能发现并继续抓取。界面上的识别数量与实际入桶数量分别记录，不混为一个指标。

### 7. 混合垃圾和连续运行

依次测试两类混合、三类混合、相邻摆放和局部遮挡。每次保存检测图和实际结果，区分以下失败类型：

- 类别识别错了。
- 类别正确，但检测框中心不适合抓取。
- 定位偏移，夹爪没有对准。
- 抓取成功，但移动途中掉落。
- 相邻物体被连带抓起。
- 放入了错误桶位。
- 托盘有残留，但复检没有检测到。

连续测试时同时记录每轮耗时、是否重新回零、是否有控制板重启以及电池状态。优先解决可重复出现的问题，再调整速度。

### 8. 完成外壳后复测

安装遮光外壳后重新进行图像测试和四个方向的运动测试。检查外壳是否压线、是否改变照明、是否影响触控和取桶。最后进行多次冷启动，验证应用启动、串口解锁、15 秒等待和第一轮投料流程。

建议随项目发布一份实测表：

| 软件/模型版本 | 测试场景 | 次数 | 正确入桶次数 | 平均耗时 | 主要失败原因 |
| --- | --- | --- | --- | --- | --- |
| 待填写 | 单目标四类 | 待测 | 待测 | 待测 | 待记录 |
| 待填写 | 同类多目标 | 待测 | 待测 | 待测 | 待记录 |
| 待填写 | 多类混合 | 待测 | 待测 | 待测 | 待记录 |
| 待填写 | 相邻/遮挡 | 待测 | 待测 | 待测 | 待记录 |

## 常见问题与待完善项

| 现象 | 优先检查 |
| --- | --- |
| 上电后不进入工作 | 是否在界面进入识别页面并发送 `'6'`，`Start_Flag` 是否约 15 秒后置位 |
| 第二台步进电机提前通电或始终没电 | PB6 高低电平、继电器触发极性、常开/常闭触点 |
| 机构到不了预期位置 | 回零、方向分支、脉冲系数、皮带张力及坐标转换偏移 |
| 第四路超声波异常 | PB15 是否按 GPIOB 初始化、模块地和 Echo 接线 |
| 空桶显示满载 | 是否把 `-1` 测量失败值参与了平均；探头是否照到框架 |
| 报文到达但没有动作 | 是否先发 `'6'`、是否混入额外回车、坐标帧长度是否正确 |
| 一次误报后还继续错误分类 | 首次识别无目标时的随机分支是否仍启用 |
| 舵机上电就撞机构 | 舵盘参考位、程序初始角和实际机械装配是否对应 |
| 两个伸缩舵机互相顶住 | 相同角度下两侧连杆安装方向是否正确 |
| 开了界面但不能识别 | 摄像头编号、串口路径、权重路径和工作目录 |
| 改分辨率后抓取位置偏移 | 是否重新标定，像素坐标是否超过三位协议范围 |
| 界面数量与实际垃圾数量不同 | 计数在动作前更新，复检路径没有相同计数逻辑 |
| 切到其他界面或重进页面后显示异常 | QML 页面状态、图像提供器连接及局部计数是否重新初始化 |

在进一步完善源码时，优先处理以下项目：

1. 修正超声波 PB15 初始化，剔除无效测距并增加真实超时。
2. 取消首次识别失败后的随机分类，增加重拍及未识别状态。
3. 增加坐标范围检查，修正 CoreXY 特定负方向分支并验证脉冲同步。
4. 将串口中断中的长动作移到主循环，补全报文错误恢复。
5. 明确回零完成反馈，完善上电后实际位置与软件原点一致性检查。
6. 将机械执行成功与界面统计分开，增加动作完成状态。
7. 评估主循环与中断共享标志的访问方式，包括 `Start_Flag`、`UART3_RxFlag` 等变量的 `volatile` 和同步处理。

这份教程依据省赛源码解释现有实现，修正片段和改进项需要应用到实际工程后重新编译、烧录及验证。未列出实测结果的部分，不视为已完成硬件验收。

## 仓库整理与资料发布

完整制作教程位于 `docs/build-guide.md`，图片统一放在 `docs/assets/`。仓库首页 `README.md` 提供制作、固件、应用和模型入口。

源码已经从省赛压缩包展开为 `firmware/stm32/` 和 `software/raspberry-pi/`；机械模型放在 `hardware/mechanical/`，内部文件名和子目录保持一致。训练与图像测试使用 `tools/vision/`，坐标标定使用 `tools/calibration/`。

完整原始资料保留在本地 `.local-archive/original/`，包括旧工程、训练数据、系统镜像、安装包、厂商资料和省赛压缩包。Git 默认忽略这个目录，账号初始化资料不会进入正常提交范围。部署模型和展示视频也仅本地保留，下载源码后应按照 `models/README.md` 与应用说明准备。

详细路径对应见 [目录迁移说明](repository-layout.md)。全项目检查使用 `python3 scripts/check_repository.py`，不连接硬件、不运行模型。

在公开发布前，还需补齐实物规格、CAD 引用验证、运行环境版本、测试结果。采购图片中的个人订单信息需另外检查；目录整理没有对图片作隐私打码。

## 致谢与第三方资料

感谢 **ccy** 完成树莓派端开发，感谢 **zsq** 学长提供 Qt 界面基础。

CoreXY 设计参考了 [Rics_3D 的 Woodcore XY-CORE](https://www.thingiverse.com/thing:2555558)。

项目使用 Ultralytics、STM32 相关库、Qt/PySide6、OpenCV 等软件，感谢相关项目与作者提供的工具和资料。

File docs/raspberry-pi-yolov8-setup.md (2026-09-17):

# 树莓派 YOLOv8 环境配置

本项目的树莓派环境配置记录，包含 SSH 远程连接、Python 编译安装和 YOLOv8 相关依赖安装。

[查看完整命令 TXT](搭建yolov8环境.txt)

## 记录的环境

| 项目 | 版本或说明 |
| --- | --- |
| 操作系统 | Ubuntu 24.04.1 LTS 桌面版 |
| Python | 3.10.16 |
| PyTorch | torch 2.0.0 |
| torchvision | 0.15.1 |
| torchaudio | 2.0.1 |
| NumPy | 1.23.5 |
| ultralytics | 安装命令未固定版本 |

以下命令按项目保存的配置记录整理，尚未在目标树莓派上重新验证。这里记录的是 YOLOv8 环境；完整 Qt 应用还需要 PySide6、pyserial 等依赖，参见 [树莓派应用说明](../software/raspberry-pi/README.md)。

## 1. 启用 SSH

在树莓派上执行：

```sh
sudo apt update

sudo apt install openssh-server

sudo systemctl enable ssh

sudo systemctl start ssh

sudo systemctl status ssh
```

状态显示 `active (running)` 表示 SSH 已启动。查看树莓派 IP：

```sh
hostname -I
```

然后在电脑端通过 VS Code 的远程连接功能连接树莓派。

如果树莓派已重装系统，电脑上仍保存了该地址对应的旧主机密钥，在确认目标设备身份后，可在电脑终端移除旧记录：

```sh
ssh-keygen -R <树莓派的IP地址>
```

将占位符替换为实际 IP，再重新连接。

## 2. 编译安装 Python 3.10.16

在树莓派上执行：

```sh
sudo apt update

sudo apt upgrade -y

sudo apt install -y build-essential libssl-dev zlib1g-dev libbz2-dev \
                    libreadline-dev libsqlite3-dev wget curl llvm \
                    libncurses5-dev libncursesw5-dev libffi-dev \
                    liblzma-dev python3-openssl git

cd ~

wget https://www.python.org/ftp/python/3.10.16/Python-3.10.16.tgz

tar -xvzf Python-3.10.16.tgz

cd Python-3.10.16

./configure --enable-optimizations

make -j 4 

sudo make altinstall

sudo update-alternatives --install /usr/bin/python3 python3 /usr/local/bin/python3.10 1
```

上述记录包含通过 `update-alternatives` 改变 `python3` 指向的操作。检查解释器版本：

```sh
python3 --version
```

记录中的预期结果：

```text
Python 3.10.16
```

## 3. 安装 PyTorch、YOLOv8 和 NumPy

```sh
sudo apt-get update

sudo apt-get upgrade

sudo apt install python3-pip

sudo pip install torch==2.0.0 torchvision==0.15.1 torchaudio==2.0.1 --index-url https://download.pytorch.org/whl/cpu -i https://mirrors.tuna.tsinghua.edu.cn/pypi/web/simple --trusted-host=https://mirrors.tuna.tsinghua.edu.cn/pypi/web/simple

sudo pip install ultralytics -i https://mirrors.tuna.tsinghua.edu.cn/pypi/web/simple --trusted-host=https://mirrors.tuna.tsinghua.edu.cn/pypi/web/simple

sudo pip install numpy==1.23.5

python3 -m pip install numpy==1.23.5
```

这里保留了记录中的版本号、镜像参数和两种 NumPy 安装写法；它们不是已经锁定并重新验证过的依赖环境。最终使用的解释器、包版本和目标平台兼容性应通过实机验证记录下来。

## 4. 接入项目运行流程

准备好模型、串口和摄像头后，按 [树莓派应用说明](../software/raspberry-pi/README.md) 启动程序。机械接线、IO 表、标定及分拣流程见 [完整制作教程](build-guide.md)。

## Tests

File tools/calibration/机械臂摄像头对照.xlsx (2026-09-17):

 | 机械臂 |  | 摄像头
 | x | y | x | y
1 | 110 | 80 | 213 | 138
2 | 60 | 80 | 327 | 139
3 | 65 | 150 | 313 | 295
4 | 43 | 168 | 365 | 336
5 | 34 | 175 | 385 | 352
6 | 26 | 58 | 403 | 89
7 | 20 | 33 | 416 | 33
8 | 56 | 43 | 336 | 56
9 | 62 | 78 | 321 | 133
10 | 89 | 98 | 262 | 179
11 | 150 | 155 | 121 | 304
12 | 142 | 87 | 141 | 152
13 | 118 | 65 | 194 | 104
14 | 97 | 73 | 244 | 123
15 | 37 | 138 | 378 | 268
16 | 49 | 141 | 351 | 274
17 | 39 | 159 | 373 | 314
18 | 18 | 163 | 420 | 324
19 | 7 | 171 | 445 | 342

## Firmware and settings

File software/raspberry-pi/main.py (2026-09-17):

import sys
import time
import cv2 as cv
from ultralytics import YOLO
import serial
import random

from PySide6.QtGui import QGuiApplication,QImage,QPixmap
from PySide6.QtQuick import QQuickImageProvider
from PySide6.QtWidgets import QWidget,QLabel
from PySide6.QtQml import QQmlApplicationEngine
from PySide6.QtCore import QThread,Slot,Signal,QObject

class VideoFrameProvider(QQuickImageProvider):
	def __init__(self):
		super().__init__(QQuickImageProvider.Image)
		self.image = QImage()

	def requestImage(self, id, size, requestedSize):
		return self.image

	def update_image(self, image):
		self.image = image

class TestSystem(QObject):
	frame_ready = Signal()
	find_trash = Signal(int, str)
	is_full = Signal(int, int, int, int)

	def __init__(self, image_provider):
		super().__init__()

		self.model = YOLO("yolo/best.pt")

		self.ser = serial.Serial("/dev/ttyAMA0", 115200)

		self.counter = 0# 拍摄照片张数
		self.total = 0# 检测到的垃圾数量
		self.number = 0# 投入垃圾序号
		self.itemClass = 0# 垃圾种类
		self.trashDict = self.trash_dict()

		# 满溢检测标志
		self.one = 0
		self.two = 0
		self.three = 0
		self.four = 0

		self.image_provider = image_provider


		self.button_thread = QThread(self)
		self.button_thread.run = self.serial_receive
		self.button_thread.start()

	def test_send(self, frame):
		results = self.model.predict(frame, conf=0.7, verbose=False)
		img_result = results[0].plot()
		img_path = f"yolo/pics/test_{self.counter}.jpg"
		cv.imwrite(img_path, img_result)
		print("已拍摄图片%d" %self.counter)

		Qframe = cv.cvtColor(img_result, cv.COLOR_BGR2RGB)
		h, w, ch = Qframe.shape
		bytes_per_line = ch * w
		img_qml = QImage(Qframe.data, w, h, bytes_per_line, QImage.Format_RGB888)
		self.image_provider.update_image(img_qml)
		self.frame_ready.emit()
		for result in results:
			boxes = result.boxes
			classes = []
			positions = []
			for box in boxes:
				self.total += 1
				item = self.trashDict.get(self.model.names[box.cls.item()], "Unknown")
				if item == "harmful":
					classes.append(item)
					positions.append(box.xywh)
				else:
					classes.insert(0, item)
					positions.insert(0, box.xywh)

				#if box.conf > conf:
				#	conf = box.conf
				#	self.itemClass = box.cls.item()
				#	position = box.xywh
			if len(classes) == 0:# 如果没有检测到物体
				break
			else:# 检测到物体
				self.itemClass = classes[0]
				position = positions[0]
				if self.total > 1:# 检测到大于一个物体
					same_flag = 1
					for other in classes:
						if self.itemClass != other:
							same_flag = 0
							break
					if same_flag == 1:# 物体全相同
						for item in classes:
							self.number += 1
							self.find_trash.emit(self.number, item)
						if self.itemClass == 'harmful':
							self.ser.write(b"1")
						elif self.itemClass == 'recycle':
							self.ser.write(b"3")
						elif self.itemClass == 'kitchen':
							self.ser.write(b"2")
						elif self.itemClass == 'others':
							self.ser.write(b"4")
					else:# 物体不全相同
						self.number += 1
						self.find_trash.emit(self.number, self.itemClass)
						sendbyte = 0
						if self.itemClass == 'harmful':
							sendbyte = 1
						elif self.itemClass == 'recycle':
							sendbyte = 3
						elif self.itemClass == 'kitchen':
							sendbyte = 2
						elif self.itemClass == 'others':
							sendbyte = 4
						pos_x = int(position[0][0])
						pos_y = int(position[0][1])
						mes = f"{pos_x:03d}" + f"{pos_y:03d}" + f"{sendbyte}"
						self.ser.write(b"5" + bytes(mes, encoding = "ascii") + b"\n")
				else:# 只检测到一个物体
					self.number += 1
					self.itemClass = classes[0]
					self.find_trash.emit(self.number, self.itemClass)
					if self.itemClass == 'harmful':
						self.ser.write(b"1")
					elif self.itemClass == 'recycle':
						self.ser.write(b"3")
					elif self.itemClass == 'kitchen':
						self.ser.write(b"2")
					elif self.itemClass == 'others':
						self.ser.write(b"4")
		if len(classes) == 0:# 没有检测到物体的处理
			self.number += 1
			randnum = random.randint(0, 9)
			print(randnum)
			self.itemClass = self.trashDict.get(self.model.names[randnum], "Unknown")
			self.find_trash.emit(self.number, self.itemClass)
			if self.itemClass == 'harmful':
				self.ser.write(b"1")
			elif self.itemClass == 'recycle':
				self.ser.write(b"3")
			elif self.itemClass == 'kitchen':
				self.ser.write(b"2")
			elif self.itemClass == 'others':
				self.ser.write(b"4")
		self.total = 0

	def check(self, frame):
		results = self.model.predict(frame, conf=0.7, verbose=False)
		img_result = results[0].plot()
		img_path = f"yolo/pics/test_{self.counter}.jpg"
		cv.imwrite(img_path, img_result)
		print("已拍摄图片%d" %self.counter)

		Qframe = cv.cvtColor(img_result, cv.COLOR_BGR2RGB)
		h, w, ch = Qframe.shape
		bytes_per_line = ch * w
		img_qml = QImage(Qframe.data, w, h, bytes_per_line, QImage.Format_RGB888)
		self.image_provider.update_image(img_qml)
		self.frame_ready.emit()
		for result in results:
			boxes = result.boxes
			classes = []
			positions = []
			for box in boxes:
				self.total += 1
				item = self.trashDict.get(self.model.names[box.cls.item()], "Unknown")
#				if item == "harmful":
#					classes.append(item)
#					positions.append(box.xywh)
#				else:
				classes.insert(0, item)
				positions.insert(0, box.xywh)
				#if box.conf > conf:
				#	conf = box.conf
				#	self.itemClass = box.cls.item()
				#	position = box.xywh
			if len(classes) == 0:# 如果没有检测到物体
				break
			else:# 检测到物体
				self.itemClass = classes[0]
				position = positions[0]
				sendbyte = 0
				if self.itemClass == 'harmful':
					sendbyte = 1
				elif self.itemClass == 'recycle':
					sendbyte = 3
				elif self.itemClass == 'kitchen':
					sendbyte = 2
				elif self.itemClass == 'others':
					sendbyte = 4
				pos_x = int(position[0][0])
				pos_y = int(position[0][1])
				mes = f"{pos_x:03d}" + f"{pos_y:03d}" + f"{sendbyte}"
				self.ser.write(b"5" + bytes(mes, encoding = "ascii") + b"\n")
		if len(classes) == 0:# 没有检测到物体的处理
			self.ser.write(b"9")
		self.total = 0

	def serial_receive(self):
		while True:
			if self.ser.in_waiting > 0:
				data = self.ser.readline().decode('utf-8').strip()
				if data == "Start":
					self.cap = cv.VideoCapture(0)
					if not self.cap.isOpened():
						print("错误：无法访问摄像头")
						exit()
					ret, frame = self.cap.read()
					if not ret:
						print("错误：无法获取画面")
						exit()
					self.counter += 1
					self.test_send(frame)
					self.cap.release()
				if data == "Check":
					self.cap = cv.VideoCapture(0)
					if not self.cap.isOpened():
						print("错误：无法访问摄像头")
						exit()
					ret, frame = self.cap.read()
					if not ret:
						print("错误：无法获取画面")
						exit()
					self.counter += 1
					self.check(frame)
					self.cap.release()
				if data == "One":
					self.one = 1
				if data == "Two":
					self.two = 1
				if data == "Three":
					self.three = 1
				if data == "Four":
					self.four = 1
				if data == "Oempty":
					self.one = 0
				if data == "Tempty":
					self.two = 0
				if data == "Rempty":
					self.three = 0
				if data == "Fempty":
					self.four = 0
				self.is_full.emit(self.one, self.two, self.three, self.four)
	def trash_dict(self):
		return {
			'battery': 'harmful',
			'drug': 'harmful',
			'plastic': 'recycle',
			'metal': 'recycle',
			'potato': 'kitchen',
			'carrot': 'kitchen',
			'daikon': 'kitchen',
			'brick': 'others',
			'cobblestone': 'others',
			'cup': 'recycle',
			'porcelain': 'others',
		}

	@Slot()
	def condense(self):
		self.ser.write(b"7")

	@Slot()
	def checkFull(self):
		self.ser.write(b"8")

	@Slot()
	def unlock(self):
		self.ser.write(b"6")

if __name__ == "__main__":
	#qml模块初始化
	app = QGuiApplication()
	view = QQmlApplicationEngine()

	image_provider = VideoFrameProvider()
	view.addImageProvider("videoFrameProvider", image_provider)

	test = TestSystem(image_provider)
	view.rootContext().setContextProperty("videoCapture", test)

	qml_file =  "qml/main.qml"
	view.load(qml_file)
	sys.exit(app.exec())

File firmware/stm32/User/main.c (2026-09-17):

#include "stm32f10x.h"    
#include "Delay.h" 
#include "OLED.h" 
#include "Low_Servo_App.h"
#include "Catch.h"
#include "stepper_motor.h"
#include "Arm_Servo_App.h"
#include "hc_sr04.h"
#include "infrared.h"
#include "UART3_OpenMV.h"
#include "workLED.h"

//uint8_t test_num;

uint8_t break_flag = 0;
uint8_t check_flag = 0;

int main(void)
{	
	workLED_Init();
	OLED_Init();
	UART3_OpenMV_Init(115200, 0, 1);		// 树莓派5通信，优先级最高
	Catch_Init();							// 机械臂初始化
	Low_Servo_Init();						// 下半部分舵机控制
	IR_Init();   							// 光幕检测初始化
	HC_SR04_Init();							// 超声波初始化
	
	Low_Servo_Reset();						// 下部分舵机复位

	Delay_s(1);	
	
	while(!UART3_GetRxFlag());
	
	while(1)
	{
		if(Start_Flag)
		{
			break;
		}
	}
		
	while(1)	
	{
		uint8_t react_data;
		
		if(!(break_flag || check_flag)) {
			workLED_turnOff();
		}
		
		while(1)
		{
			IR_Detection_Process();
        
			if (IR_Detected || break_flag || check_flag)
			{
				workLED_turnOn();
				break;
			}
		}
		
		if(!(break_flag || check_flag)) Delay_s(2);

//		Delay_s(1);
		if(check_flag == 1) {
			UART3_OpenMV_SendString("Check\n");
		}
		else {
			UART3_OpenMV_SendString("Start\n");
		}
		
		while(!UART3_GetRxFlag());

		react_data = UART3_GetRxData();
		
		if(react_data == '6') {
//			OLED_ShowNum(1, 1, test_num++, 3);
			continue;
		}
		
		Delay_ms(100);
		
		Low_Servo_SetGuard(80);
		
		if(react_data == '9') {
			HC_SR04_Get_Average_Distances();

			check_flag = 0;
			Low_Servo_Reset();
			continue;
		}
		else if(react_data != '\n') {
			Low_Servo_React(react_data & 0x0F);
			Delay_s(1);
			

			break_flag = 0;
			check_flag = 1;
		}
		else {
			RxInfo info = UART3_GetRxInfo();
			Catch(info.x, info.y, 85, info.type);
			if(check_flag == 0) {
				break_flag = 1;
			}

		}
		
		
		
		Low_Servo_Reset();
		
	}
}	

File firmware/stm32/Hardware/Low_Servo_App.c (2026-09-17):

#include "servo_drive.h"
#include "Delay.h"

#define DEGREE_ 46
#define DEGREE_HORIZONTAL 90
#define DEGREE_VERTICAL 94
#define DEGREE_GUARD 52
#define ROTATE_DELAY 20

 /**
 * @brief  设置水平舵机角度
 * @param  角度
 * @retval None
 */
void Low_Servo_SetCompareHorizontal(float DEGREE)
{
  TIM2_PWM_SetCompare1(DEGREE / 180 * 2000 + 500);
}

 /**
 * @brief  设置竖直舵机角度
 * @param  角度
 * @retval None
 */
void Low_Servo_SetCompareVertical(float DEGREE)
{
  TIM2_PWM_SetCompare2(DEGREE / 180 * 2000 + 500);
}

 /**
 * @brief  设置挡板舵机角度
 * @param  角度
 * @retval None
 */
void Low_Servo_SetGuard(float DEGREE)
{
  TIM2_PWM_SetCompare3(DEGREE / 180 * 2000 + 500);
}

 /**
 * @brief  角度延时旋转
 * @param  角度
 * @retval None
 */
void Low_Servo_RotateHorizontal(float DEGREE)
{
  uint8_t i;
  if(DEGREE > 90){
    for(i = 91; i <= DEGREE; i ++){
      Low_Servo_SetCompareHorizontal(i);
      Delay_ms(ROTATE_DELAY);
    }
  }
  else{
    for(i = 89; i >= DEGREE; i --){
      Low_Servo_SetCompareHorizontal(i);
      Delay_ms(ROTATE_DELAY);
    }
  }
}

void Low_Servo_RotateReset(void)
{
	uint8_t i;
	for(i = 46; i <= 90; i ++){
      Low_Servo_SetCompareHorizontal(i);
      Delay_ms(ROTATE_DELAY);
    }
}

 /**
 * @brief  Low_Servo 舵机复位
 * @param  None
 * @retval None
 */
void Horizontal_and_Vertical_Reset(void)
{
  Low_Servo_SetCompareHorizontal(DEGREE_HORIZONTAL);
  Low_Servo_SetCompareVertical(DEGREE_VERTICAL);
}

 /**
 * @brief  Low_Servo 舵机复位
 * @param  None
 * @retval None
 */
void Low_Servo_Reset(void)
{
  Low_Servo_SetCompareHorizontal(DEGREE_HORIZONTAL);
  Low_Servo_SetCompareVertical(DEGREE_VERTICAL);
	Delay_ms(200);
  Low_Servo_SetGuard(DEGREE_GUARD);
}

 /**
 * @brief  Low_Servo 舵机初始化
 * @param  None
 * @retval None
 */
void Low_Servo_Init(void)
{
  TIM2_PWM_Init();
  Low_Servo_Reset();
}

 /**
 * @brief  Low_Servo 对输入不同数字倾斜不同角度
 * @param  1234 数字
 * @retval None
 */
void Low_Servo_React(uint8_t NUM)
{
  if(NUM == 0){
    Low_Servo_Reset();
  }
  else if(NUM == 1){
    Low_Servo_RotateHorizontal(DEGREE_HORIZONTAL - 45);
    Low_Servo_SetCompareVertical(DEGREE_VERTICAL + DEGREE_);
  }
  else if(NUM == 2){
    Low_Servo_RotateHorizontal(DEGREE_HORIZONTAL + 45);
    Low_Servo_SetCompareVertical(DEGREE_VERTICAL + DEGREE_);
  }
  else if(NUM == 3){
    Low_Servo_RotateHorizontal(DEGREE_HORIZONTAL - 45);
    Low_Servo_SetCompareVertical(DEGREE_VERTICAL - DEGREE_);
  }
  else if(NUM == 4){
    Low_Servo_RotateHorizontal(DEGREE_HORIZONTAL + 45);
    Low_Servo_SetCompareVertical(DEGREE_VERTICAL - DEGREE_);
  }
}

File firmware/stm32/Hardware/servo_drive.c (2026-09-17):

#include "stm32f10x.h"                  	// Device header

 /**
 * @brief  TIM2 PWM 初始化
 * @param  None
 * @retval None
 */
void TIM2_PWM_Init(void)
{
  //开启时钟
  RCC_APB1PeriphClockCmd(RCC_APB1Periph_TIM2, ENABLE);
  RCC_APB2PeriphClockCmd(RCC_APB2Periph_GPIOA, ENABLE);

  //配置GPIO
  GPIO_InitTypeDef GPIO_InitStructure;
  GPIO_InitStructure.GPIO_Pin = GPIO_Pin_0 | GPIO_Pin_1 | GPIO_Pin_2;
  GPIO_InitStructure.GPIO_Mode = GPIO_Mode_AF_PP;
  GPIO_InitStructure.GPIO_Speed = GPIO_Speed_50MHz;
  GPIO_Init(GPIOA, &GPIO_InitStructure);

  
  //配置定时器
  TIM_InternalClockConfig(TIM2);

  TIM_TimeBaseInitTypeDef TIM_TimeBaseInitStructure;
  TIM_TimeBaseInitStructure.TIM_ClockDivision = TIM_CKD_DIV1;
  TIM_TimeBaseInitStructure.TIM_CounterMode = TIM_CounterMode_Up;
  TIM_TimeBaseInitStructure.TIM_Period = 20000 - 1;
  TIM_TimeBaseInitStructure.TIM_Prescaler = 72 - 1;
  TIM_TimeBaseInitStructure.TIM_RepetitionCounter = 0;
  TIM_TimeBaseInit(TIM2, &TIM_TimeBaseInitStructure);

  TIM_OCInitTypeDef TIM_OCInitStructure;
  TIM_OCStructInit(&TIM_OCInitStructure);
  TIM_OCInitStructure.TIM_OCMode = TIM_OCMode_PWM1;
  TIM_OCInitStructure.TIM_OCPolarity = TIM_OCPolarity_High;
  TIM_OCInitStructure.TIM_OutputState = TIM_OutputState_Enable;
  TIM_OCInitStructure.TIM_Pulse = 0;
  TIM_OC1Init(TIM2, &TIM_OCInitStructure);
  TIM_OC2Init(TIM2, &TIM_OCInitStructure);
  TIM_OC3Init(TIM2, &TIM_OCInitStructure);

  TIM_Cmd(TIM2, ENABLE);
}

 /**
 * @brief  TIM2 PWM 输出口1的占空比
 * @param  占空比
 * @retval None
 */
void TIM2_PWM_SetCompare1(uint16_t COMPARE)
{
  TIM_SetCompare1(TIM2, COMPARE);
}

 /**
 * @brief  TIM2 PWM 输出口2的占空比
 * @param  占空比
 * @retval None
 */
void TIM2_PWM_SetCompare2(uint16_t COMPARE)
{
  TIM_SetCompare2(TIM2, COMPARE);
}

 /**
 * @brief  TIM2 PWM 输出口3的占空比
 * @param  占空比
 * @retval None
 */
void TIM2_PWM_SetCompare3(uint16_t COMPARE)
{
  TIM_SetCompare3(TIM2, COMPARE);
}

 /**
 * @brief  TIM3 PWM 初始化
 * @param  None
 * @retval None
 */
void TIM3_PWM_Init(void)
{
  //开启时钟
  RCC_APB1PeriphClockCmd(RCC_APB1Periph_TIM3, ENABLE);
  RCC_APB2PeriphClockCmd(RCC_APB2Periph_GPIOA, ENABLE);
  RCC_APB2PeriphClockCmd(RCC_APB2Periph_GPIOB, ENABLE);

  //配置GPIO
  GPIO_InitTypeDef GPIO_InitStructure;
  GPIO_InitStructure.GPIO_Pin = GPIO_Pin_6 | GPIO_Pin_7;
  GPIO_InitStructure.GPIO_Mode = GPIO_Mode_AF_PP;
  GPIO_InitStructure.GPIO_Speed = GPIO_Speed_50MHz;
  GPIO_Init(GPIOA, &GPIO_InitStructure);

  GPIO_InitStructure.GPIO_Pin = GPIO_Pin_0 | GPIO_Pin_1;
  GPIO_InitStructure.GPIO_Mode = GPIO_Mode_AF_PP;
  GPIO_InitStructure.GPIO_Speed = GPIO_Speed_50MHz;
  GPIO_Init(GPIOB, &GPIO_InitStructure);
  
  //配置定时器
  TIM_InternalClockConfig(TIM3);

  TIM_TimeBaseInitTypeDef TIM_TimeBaseInitStructure;
  TIM_TimeBaseInitStructure.TIM_ClockDivision = TIM_CKD_DIV1;
  TIM_TimeBaseInitStructure.TIM_CounterMode = TIM_CounterMode_Up;
  TIM_TimeBaseInitStructure.TIM_Period = 20000 - 1;
  TIM_TimeBaseInitStructure.TIM_Prescaler = 72 - 1;
  TIM_TimeBaseInitStructure.TIM_RepetitionCounter = 0;
  TIM_TimeBaseInit(TIM3, &TIM_TimeBaseInitStructure);

  TIM_OCInitTypeDef TIM_OCInitStructure;
  TIM_OCStructInit(&TIM_OCInitStructure);
  TIM_OCInitStructure.TIM_OCMode = TIM_OCMode_PWM1;
  TIM_OCInitStructure.TIM_OCPolarity = TIM_OCPolarity_High;
  TIM_OCInitStructure.TIM_OutputState = TIM_OutputState_Enable;
  TIM_OCInitStructure.TIM_Pulse = 0;
  
  TIM_OC1Init(TIM3, &TIM_OCInitStructure);
  TIM_OC2Init(TIM3, &TIM_OCInitStructure);
  TIM_OC3Init(TIM3, &TIM_OCInitStructure);
  TIM_OC4Init(TIM3, &TIM_OCInitStructure);

  TIM_Cmd(TIM3, ENABLE);
}

 /**
 * @brief  TIM3 PWM 输出口1的占空比
 * @param  占空比
 * @retval None
 */
void TIM3_PWM_SetCompare1(uint16_t COMPARE)
{
  TIM_SetCompare1(TIM3, COMPARE);
}

 /**
 * @brief  TIM3 PWM 输出口2的占空比
 * @param  占空比
 * @retval None
 */
void TIM3_PWM_SetCompare2(uint16_t COMPARE)
{
  TIM_SetCompare2(TIM3, COMPARE);
}

 /**
 * @brief  TIM3 PWM 输出口3的占空比
 * @param  占空比
 * @retval None
 */
void TIM3_PWM_SetCompare3(uint16_t COMPARE)
{
  TIM_SetCompare3(TIM3, COMPARE);
}

 /**
 * @brief  TIM3 PWM 输出口4的占空比
 * @param  占空比
 * @retval None
 */
void TIM3_PWM_SetCompare4(uint16_t COMPARE)
{
  TIM_SetCompare4(TIM3, COMPARE);
}
